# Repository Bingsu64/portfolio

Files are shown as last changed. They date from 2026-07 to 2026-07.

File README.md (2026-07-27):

# Portfolio
This repository contains design files from student engineering projects at [ARIS (Akademische Raumfahrt Initiative Schweiz)](https://aris-space.ch/).
I have only included files and reports where I have 100% ownership and have at least been reviewed for manufacturing.

## Project HELVETIA - Recovery Electronics
[This folder ](https://github.com/Bingsu64/portfolio/tree/main/HELVETIA_REC_PCB)
contains the PCB schematic and layout files for the auxiliary power-switching and PWM-generation board used in the recovery system of our hybrid sounding rocket for SACUP 2022 (where the team placed 2nd in the 30k ft category). Additionally, a test report has been included detailing our process to test and validate the system to assure reliability and system safety.

## Project ODYSSEY - Avionics
[This folder ](https://github.com/Bingsu64/portfolio/tree/main/ODY_5V_Board)
contains the PCB design files for the block and schematics documentation of a 5V power module for a modularized flight computer architecture of a Karman-Line, bi-liquid rocket system.
Even though it was never manufactured due to premature project conclusion due to budget constraints, it had been peer-reviewed and improved drastically for legibility and documentation purposes.

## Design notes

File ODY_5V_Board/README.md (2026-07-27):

# Project ODYSSEY
This folder contains the PCB schematic and block documentation for a modular 5V power module designed for a modularized flight computer architecture 
intended for a Karman-Line, bi-liquid rocket system.  

Status: R&D / Preliminary Design Phase (Peer-Reviewed, Unmanufactured due to project budget constraints)

## ODYSSEY Avionics
Project ODYSSEY was an ambitious flagship initiative at ARIS aimed at developing a bi-liquid rocket to reach the Karman line (100km altitude).  
 - To support a complex, modularized flight computer architecture, reliable local power regulation was essential.
 - My specific ownership focused on designing the 5V power module block, ensuring stable power delivery and low noise sensitivity
 - Further focus on reliability by implementing redundancy, monitoring, and diagnostics capabilities for fault handling

|  |
| :--: |
| *Figure 1: Block Diagram of the 5V Power Module* |

## Design Readiness
Although the project concluded prematurely due to budget constraints and organizational restructuring, before physical manufacturing could take place,
the schematic underwent a rigorous formal peer-review with senior ARIS team members and technical leads. Based on review feedback, the documentation and net-labeling were drastically improved for legibility, component footprint verification, and manufacturability.

## Final Learnings
 - Learned how to design power electronics strictly to specification and system requirements before physical hardware ever exists.
 - Gained valuable experience defending schematic architecture, component choices, and safety margins during peer-review gates.

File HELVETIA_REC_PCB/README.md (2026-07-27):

# Project HELVETIA
I designed and validated the auxiliary recovery PCB for Project HELVETIA responsible for power distribution, deployment actuation, and servo PWM generation for the recovery system.
Project HELVETIA's mission was to successfully build, launch, and safely recover our rocket at the Spaceport America Cup 2022 (SACUP). 
It was designed to reach an apogee of 30,000ft with a total impulse of 40,960Ns.

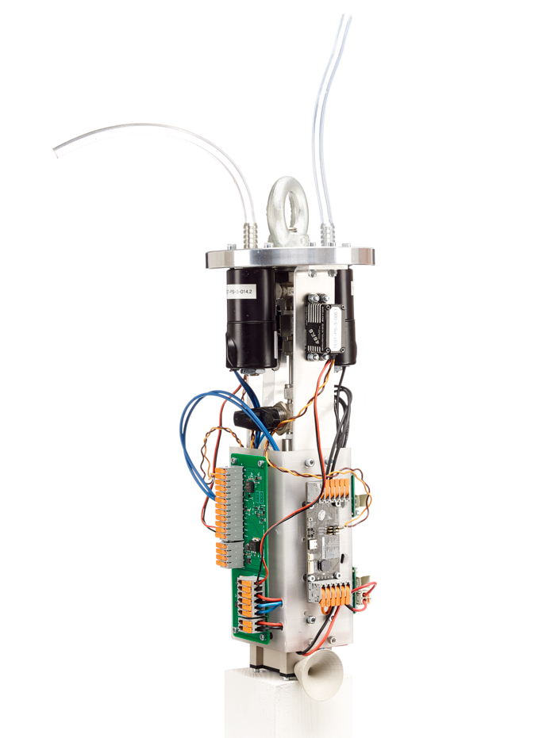
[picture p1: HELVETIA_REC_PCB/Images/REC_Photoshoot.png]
|  |
| :--: |
| *Figure 1: Picture of the sub-bulkhead assembly of the recovery fairing* |

## Recovery System
To briefly contextualize, here is an overview of the recovery system section:
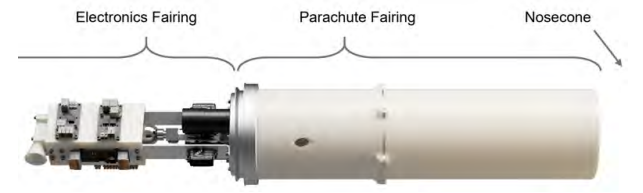
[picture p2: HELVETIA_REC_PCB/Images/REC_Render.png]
|  |
| :--: |
| *Figure 2: Render of the Recovery Section of the rocket* |

After apogee detection, the drogue parachute is deployed by CO2 separation of the nosecone. This is actuated by solenoid valves powered through switching MOSFET's on the PCB.
For the main parachute deployment, servo motors are controlled to pull open a snap shackle mechanism. They are controlled by a PWM signal generated by the board.
Due to the competition requirements, our team utilized a Commercial Off-The-Shelf (COTS) flight computer for primary sensor logging.
To bridge the actuation and power needs, I designed a dedicated auxiliary board with Altium Designer, responsible for:
 - Power Distribution and Switching: Safely arming the system and switching power rails for deployment mechanisms
 - PWM Generation: Creating precise pulse-width modulation signals for servo motor control without requiring an onboard microcontroller (due to chip shortage)
 - Mission Reliability: Total Redundancy between the COTS and Student Researched and Developed (SRAD) flight computer to ensure reliable and safe recovery operations

Note on Avionics Architecture: While SACUP regulations mandated the use of a standard COTS flight computer (TeleMega) for official mission data logging, 
our project leadership also instituted an internal requirement to test a newly student-researched and developed (SRAD) flight computer. 
Project HELVETIA successfully served as the foundational flight-test vehicle, providing the critical empirical telemetry needed to prove the reliability 
of that SRAD flight computer to regulatory officials. Within this architecture, my direct ownership and design scope focused entirely on the auxiliary power-switching, 
PWM generation, and robust actuation hardware required for safe recovery execution.

## System Integration & Flight Validation
This auxiliary hardware was integrated directly into the rocket's recovery loop as a mission critical interface to manage physical deployment for both drogue and main parachute.
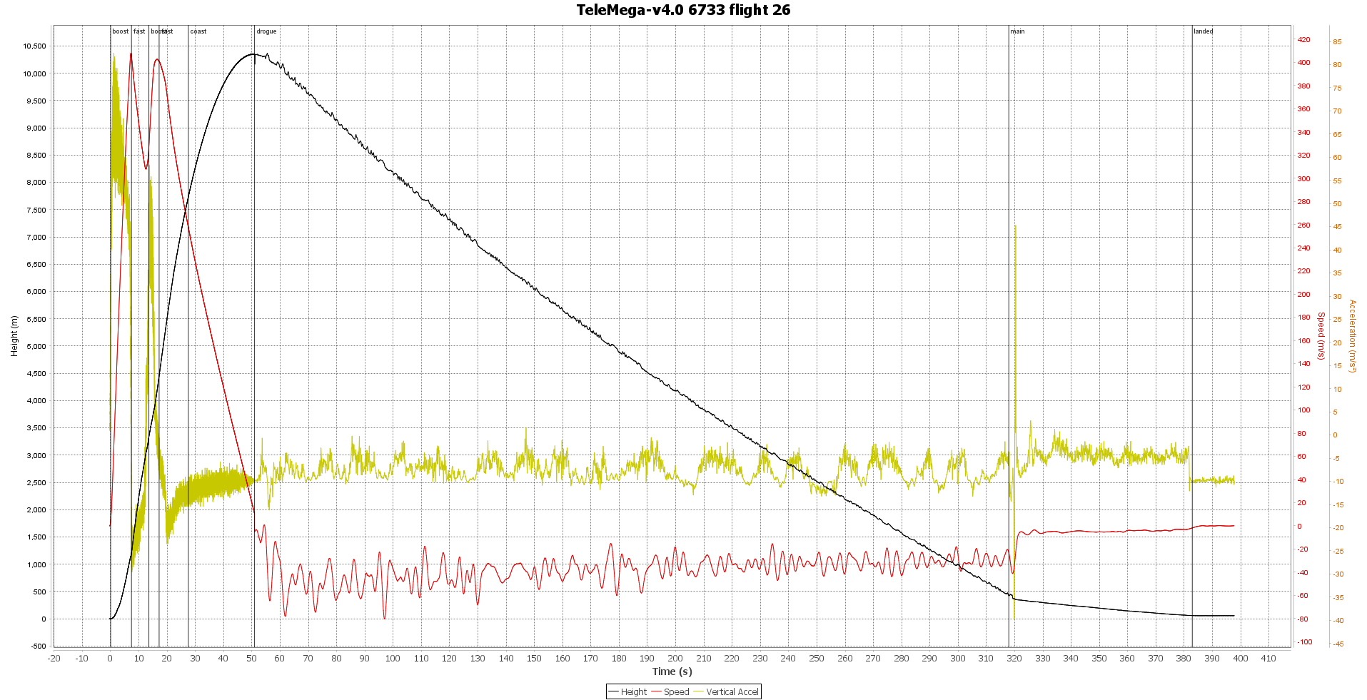
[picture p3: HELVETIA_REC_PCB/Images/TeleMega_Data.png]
|  |
| :--: |
| *Figure 3: COTS flight computer telemetry data of the flight during the SACUP competition* |

 - Beyond standard telemetry verification, our primary design and operational goal for the recovery team was simple: make a recovery system that just works
 - As the first team in ARIS history to successfully and safely land and recover our rocket, every testing procedure, safety checklist, and power-switching constraint was engineered around eliminating single-point failures
 - Flight data and test logs confirmed that the auxiliary power and actuation hardware executed deployment flawlessly under real flight conditions, securing 2nd place in the 30k ft category at SACUP 2022

## Key Takeaways & Engineering Lessons
 - Harsh Environment Design: Learned firsthand how physical vibrations and high-g forces dictate component selection, trace sizing, and layout constraints
 - System Simplicity: Saw the direct impact on system robustness by making a design simple
 - End-to-End Ownership: Managed the full lifecycle of a mission-critical PCB from initial schematic capture and layout to manufacturing, assembly, and bench/field verification

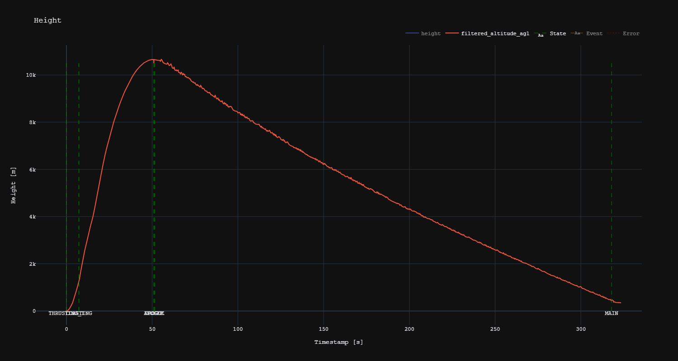
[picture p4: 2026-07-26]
HELVETIA_REC_PCB/Images/newplot.png

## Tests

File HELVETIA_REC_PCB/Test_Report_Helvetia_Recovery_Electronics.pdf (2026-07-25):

Title: | Recovery Electronics
ID: | ReEl01
Issue: | 1
Date: | 26-07-24
Page: | 1 of 42

© Project HELVETIA. This document shall not be used for other purposes than those for which it was

established. No unauthorized distribution, dissemination or disclosure.

# Recovery Electronics Full Test

Title: | Electronics Full Test Report
Project: | HELVETIA
Filename: | Test_Report_Helvetia_Recovery_Electronics
Prepared by: | Fabian Kolodziej, Dongkyu Lee, Xuanting Meng
Checked by: | Alexandros Karadeloglou, François Martin-Monier

## TEST DATA

General Information

Test – ID: | ReEl01
Subteam: | Recovery | Subsubteam: | Electronics

Introduction

This test report includes all functionality, quantity and partial system tests that have

been conducted during the testing campaign. These also encompass partial

system analyses with a focus on electronics for tests that already have a general

test report. The report aims to present procedural aspects, test data and explain

design choices.

Date: | 26-07-24
Page: | 2 of 42

© Project HELVETIA. This document shall not be used for other purposes than those for which it was

## Table of Contents

Inhalt | Error! Bookmark not defined.

Date: | 26-07-24
Page: | 3 of 42

© Project HELVETIA. This document shall not be used for other purposes than those for which it was

## 1 TEST Preparation

## 1.1 Attending People

Name | Function
Fabian Kolodziej | Test Execution
Dongkyu Lee | Test Logging
Xuanting Meng | Test Execution

## 1.2 Safety Concept

### 1.2.1 Safety Gear

Gear | Further specifications | Status
Protective Glasses | | ☐
Protective Gloves | | ☐

## 1.3 Materials

### 1.3.1 Rocket Parts

Part/Assembly | Responsible Subteams | Status
Auxiliary Board | Recovery | ☐
Flight Computers | Recovery | ☐

Date: | 26-07-24
Page: | 4 of 42

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

Arming Electronics | Recovery | ☐
Valves, Servo Motors | Recovery | ☐
Power Switching Boards | Recovery, Avionics | ☐

### 1.3.2 Equipment

Equipment | Further specifications | Status
Multimeter | A portable oscilloscope which doubles as a multimeter | ☐
LiPo-Charger | | ☐
Oscilloscope | | ☐
Laptop | With required software and cables | ☐
Camera | | ☐
Bench Power Supply | | ☐

## 1.4 Location

Short Description of the Test Location

The test locations were different for each test performed. Functionality and quantity tests

were all conducted in free working spaces that provide basic electronics testing

equipment.

Date: | 26-07-24
Page: | 5 of 42

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

Provided at the Test Location

Testing equipment which includes the equipment stated in 1.3.3.

Possible Environmental influx to the Test at the Location and vice versa

No general influx on functionality.

Signal interference by devices and metallic structures in the vicinity.

### 1.4.1 Environmental Conditions

| Actual values | Acceptable range
Weather | Inside | Any
Temperature | 20°C | Comfortable for People

Other notes

### 1.4.2 Comparison to the Launch Condition

Different Location -> Different GPS Signals

Sand could get into connectors so that assembly could prove to be more difficult

Date: | 26-07-24
Page: | 6 of 42

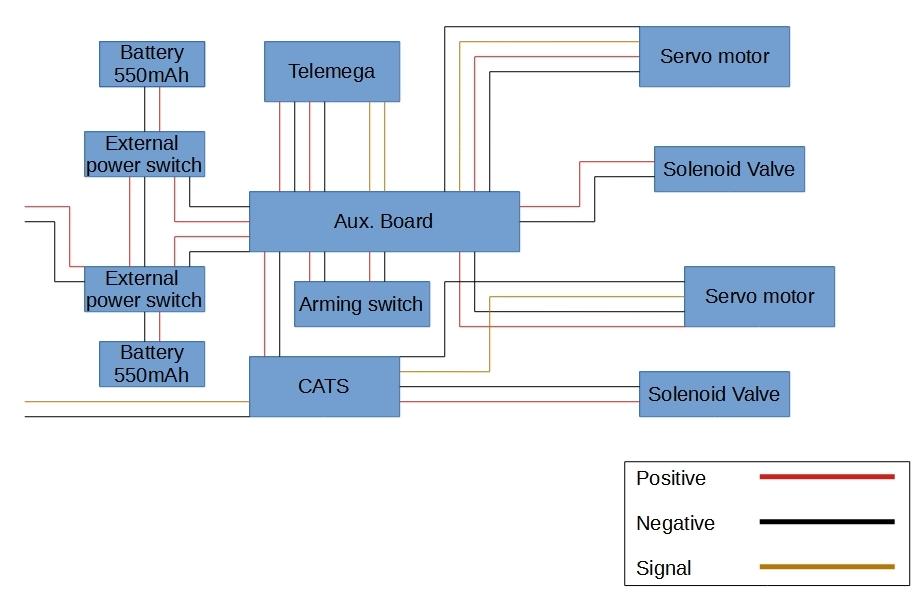
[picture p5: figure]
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

## 1.5 Setup

Setup

Description

The system consists of one auxiliary board, two power switching boards each connected

to a separate battery that power one COTS (TeleMega) and one SRAD (CATS) flight

computer respectively. Both arming switches are connected to the auxiliary board that

houses two separated systems. The servo motors are attached to aluminium L-pieces that

are connect the electronics holder to the bulkhead.

The power for both valves and servos are connected to the auxiliary board, except the

solenoid valve on the SRAD side which is directly connected to the CATS (SRAD) flight

computer.

The arming switches are housed in an arming case that is attached at the bottom of the

holder.

Wiring Diagram

Date: | 26-07-24
Page: | 7 of 42

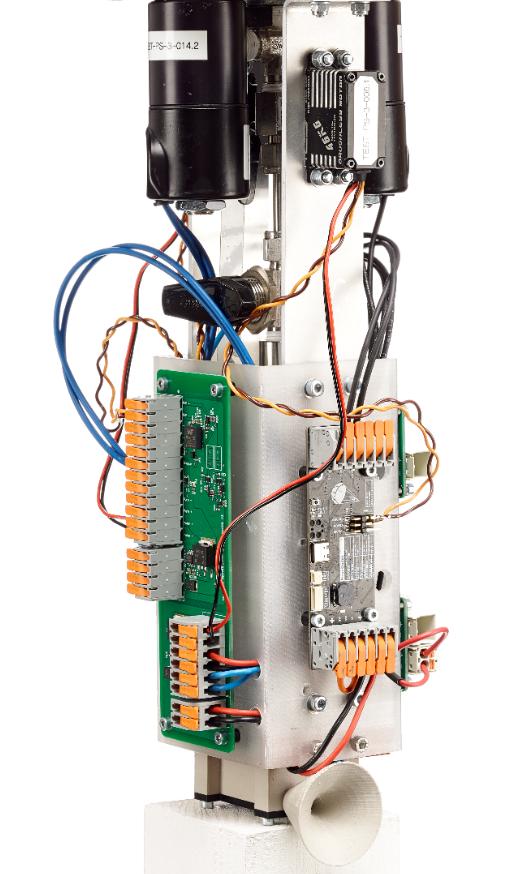
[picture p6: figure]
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

Picture

### 1.5.1 Pre-Test Checks for the Setup

What needs to be checked to ensure the success of the test?

Item | Comments | Status
Assembly Procedure | | ☐
Arming Checklist | | ☐

Date: | 26-07-24
Page: | 8 of 42

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

## 2 MAIN TESTS

## 2.1 Functionality Tests

Setup:

For general functionality tests of our system, the relevant parts will be

assembled as necessary. The basic setup is described and explained in the

previous chapter. Each unique setup is illustrated with a picture at the

beginning of each individual test subchapter.

Purpose of Test:

The following tests are performed to test and confirm the capability and

functionality of the system. This is to identify any flaws in the current concept

and design. A functionality test of the entire system requires a variety of

different tests that validify small parts of the system so that problems can only

occur in isolated and controlled instances.

### 2.1.1 Auxiliary Board Functionality Test

Purpose of Test:

During the armed state, all in- and outputs of the board are strictly defined and

need to be within an expected range. As such, probing the board for its

voltage levels and potential bridges is imperative to identify any electrical

errors that could later lead to greater failure modes and cause harm to

connected devices.

Date: | 26-07-24
Page: | 9 of 42

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

Functionality Checklist:

Procedure | Value | Status
Battery Connector Inputs ‘+’ and ‘-‘ must not be bridged | Twice for both circuits | ☐
After connecting batteries to input, voltage between input pins needs to be measured | 12V | ☐
Test arming circuits by shorting ‘Arm+’ and ‘Arm-‘ with a jumper cable | 12V | ☐
Measure voltage between ‘CATS+’ and ‘CATS-‘ | 12V | ☐
Measure voltage between ‘Motor+’ and ‘Motor-‘ | 12V | ☐
Measure voltage between ‘Pyro+’ and ‘Pyro-’ | 12V | ☐
Measure voltage between both ‘Valve’ connectors | 0V | ☐
Measure voltage between ‘Tele+’ and ‘TM-’ | 3.7V | ☐

Results:

Parameters | Value
U(+, -) | 12.2V (LiPo)
Arming Circuit | Non-functional
U(CATS+, CATS-) | 9.78V
U(Motor+, Motor-) | 9.78V
U(Pyro Battery, GND) | 9.78V

Date: | 26-07-24
Page: | 10 of 42

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

U(12V, GND) | 9.78V
U(3.7V, GND) | 3.716V
LED’s | All Functional

Conclusion:

The arming did not work as intended when opening and shorting the arming

inputs. The MosFET’s did not open when the arming switches were turned off.

This lead to the assumption that either the MosFET’s were malfunctional or

the circuit design had an issue. It turns out that the manufacturer PCB design

files were wrong. The Drain and Source were interchanged for both

schematics and footprints so that the MosFET effectively let current through its

protector diode.

Mitigation:

After identifying the issue, the amount of LED’s has been increased for safety

and easier problem detection. Furthermore, the schematics and footprints

have been corrected in a new version of the board (RecoveryBoard_V3).

Results of Retest of V2 boards:

Parameters | Value
U(+, -) | 12.2V (LiPo)
Arming Circuit | Functional
U(CATS+, CATS-) | 12V

Date: | 26-07-24
Page: | 11 of 42

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

U(Motor+, Motor-) | 12V
U(Pyro Battery, GND) | 12V
U(12V, GND) | 12V
U(3.7V, GND) | 3.716V
LED’s | All Functional

Conclusion:

With the new version of the boards, the arming circuit was functional and the

MosFET switched with no issues. Now instead of the questionable 9.7V, we

got the full 12V provided. As such, the full general power functionality of the

board was confirmed.

### 2.1.2 PWM Modulation Test

Purpose of Test:

For the deployment of the main parachute, the second deployment event, a

pulse-width modulation (PWM) signal is used. This in turn controls the position

of the servor motor arm. As the PWM outputs on the TeleMega (COTS) flight

computer have not been fully implemented yet, a PWM modulator circuit has

been implemented on the auxiliary board and needs to be tested. Due to the

servo motors missing datasheets, the PWM range is yet to be identified. For

this reason, trimmers have been implemented on the board to match the PWM

signal to any range between 0% to 100%.

Date: | 26-07-24
Page: | 12 of 42

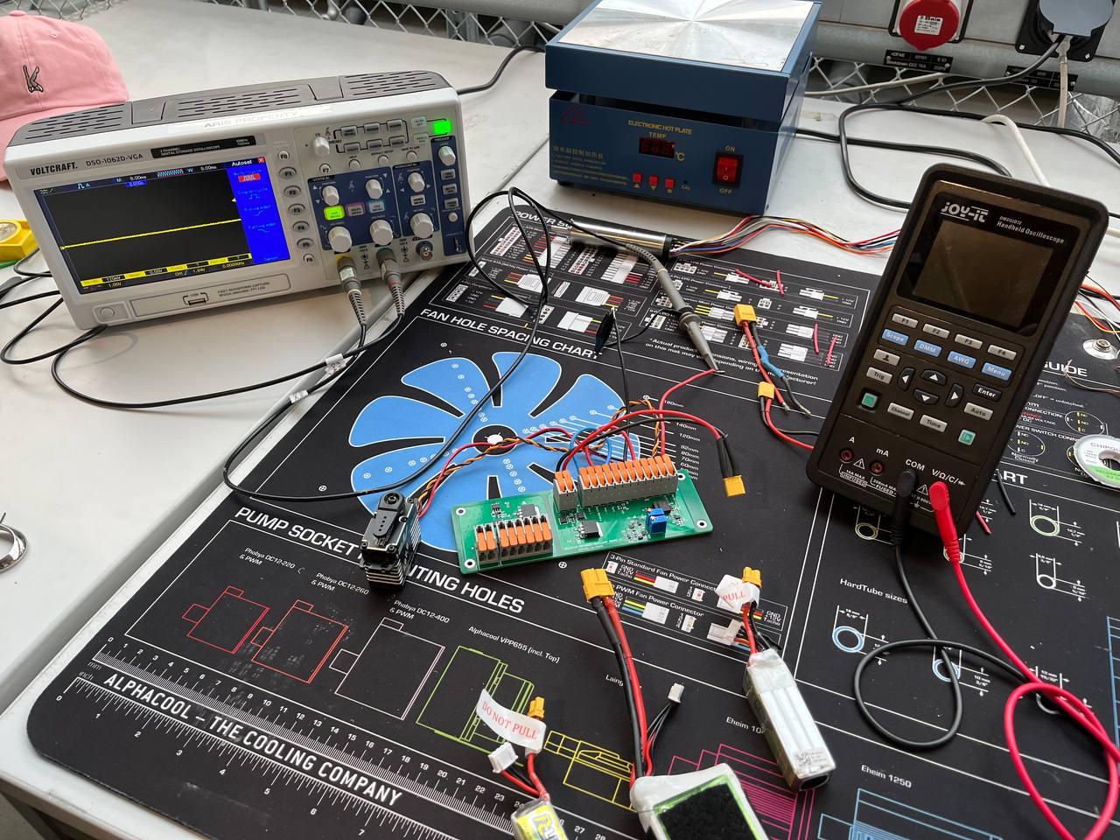
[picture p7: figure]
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

Setup change:

Figure 2.1 Servo Motor PWM Input connected to an oscilloscope

PWM Modulation Test Procedure:

Procedure | Value | Status
Pull the Arming Pin | System Armed | ☐
Connect an oscilloscope to the connectors ‘Servo’ and ‘GND’ | | ☐
Measure the signal for position 1 (Default position) | Servo Default | ☐

Date: | 26-07-24
Page: | 13 of 42

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

Turn the trimmer to see changes and try to match signal to 5% duty (usual minimum value of conventional PWM signal ranges) | | ☐
Connect connector ‘Pyro’ to ‘GND’ | | ☐
Measure the signal for position 2 (Deployment active) | Servo Deployed | ☐
Turn the trimmer to see changes and try to match signal to 10% duty (usual maximum value of conventional PWM signal ranges) | | ☐
Insert Arming Pin | System Disarmed | ☐

Results:

Parameters | Value
Frequency | 50.12Hz
Voltage Logic High | 3.7V
Voltage Logic Low | 0V
PWM Duty Cycle 1 | 15%
PWM Duty Cycle 2 | 25%
Servo Arm Position 1 | Out of Range
Servo Arm Position 2 | Out of Range
MosFET 1 | Non-Functional
MosFET 2 | Functional

Date: | 26-07-24
Page: | 14 of 42

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

Conclusion:

As the switching between the ‘Default’ and ‘Deployed’ modes was not working

as intended, the switching power MosFET’s were investigated. It turned out

that the MosFET 1 being non-functional was due to the gate driver. The output

of the gate driver was lower than what it stated in the datasheet, which led to

the MosFET 1 switch never opening and as a result, never switching.

Therefore, for ‘Deployed’ mode, when ‘Pyro’ is grounded, the resistors were

set in parallel and thus duty increased instead of getting controlled by a set

trimmer.

Furthermore, even during ‘Default’ mode in which MosFET 2 is open and

MosFET 1 is closed, the duty was out of the operating range of the servos.

The cause is the resistor at the ‘MOD’ input of the LTC6992 IC being too large

which led to a higher voltage which in turn leads to higher duties.

Mitigation:

By removing the 10k resistor at the input of the gate driver, both voltages on

input and output sides of the driver are increased. Consequently, the voltage

difference between Gate and Source lies below the threshold voltage of 0.8V

and the MosFET switches.

As the voltage across the resistor at the MOD input of the LTC6992 IC and the

duty are closely related, changing the 1.2k resistor to a 330Ohm should also

lower the resulting duty and thus the duties should enter the operating range

of the servo motors.

Results of Retest (V2):

Parameters | Value
Frequency | 50.12Hz

Date: | 26-07-24
Page: | 15 of 42

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

Voltage Logic High | 3.7V
Voltage Logic Low | 0V
PWM Duty Cycle 1 | 2%
PWM Duty Cycle 2 | 13%
Servo Arm Orientation 1 | Up
Servo Arm Orientation 2 | Down
MosFET 1 | Functional
MosFET 2 | Functional

Conclusion:

With the new changes, the PWM modulating circuit on the auxiliary board V2,

successfully switched and controlled the servo motors so that we got two

stable positions for the servo motor arms.

### 2.1.3 Ground Tests

Purpose of Test:

To ensure safe and reliable deployment of both drogue and main parachutes,

the system needs to be sufficiently tested on the ground before it may be used

in any real flight test. The capability of the system to carry out the mission in its

full capacity is essential and most of it can be tested on the ground.

Date: | 26-07-24
Page: | 16 of 42

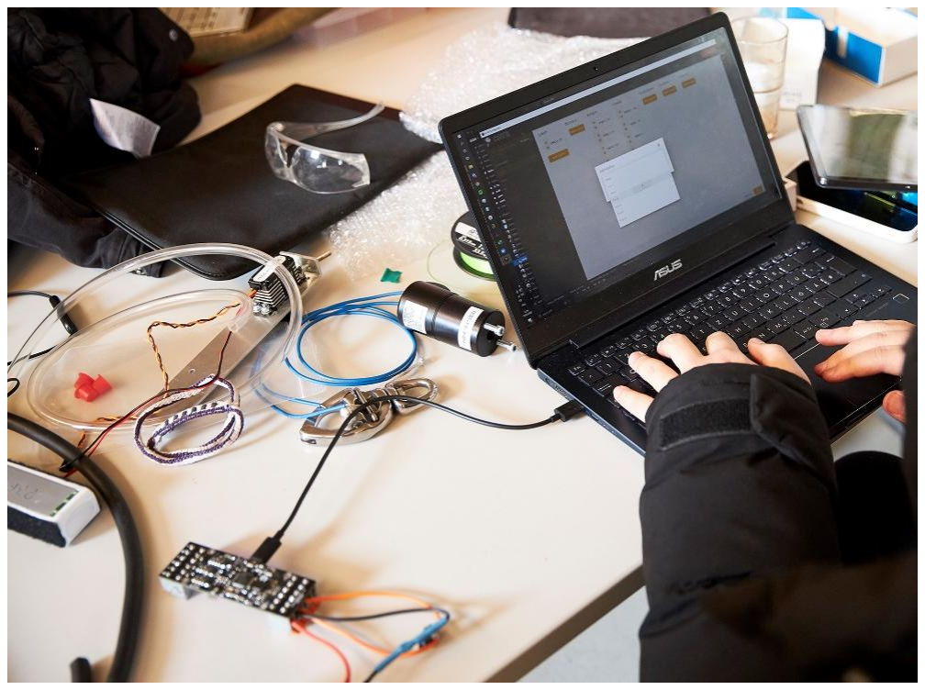
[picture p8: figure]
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

The CATS (SRAD) has been tested by setting up a timer to trigger the events

by logic. As for the TeleMega (COTS), all ground tests can be done by

manually triggering the pyro channels in question.

Setup Change:

Figure 2.2 Programming CATS (SRAD) FC for ground tests. The valves and Motors can be directly connected to flight computer.

Ground Test Procedure (CATS):

Procedure | Comments | Status
Configure CATS (SRAD) Flight Computer (Ground Test configuration) | | ☐
Pull the Arming Pin | System Armed | ☐
Wait for Ready State of the CATS Flight Computer | | ☐
Wait 10 seconds for Solenoid Valve Actuation | Drogue Deployed | ☐

Date: | 26-07-24
Page: | 17 of 42

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

Wait 5 more seconds for Servo Motor Actuation | Main Deployed | ☐
Insert Arming Pin | System Disarmed | ☐

Results:

Parameters | Value
Valve Actuation | Successful (3s)
Servo Motor Actuation | 30° to 150°

Conclusion:

Valve actuation worked flawlessly for 3 seconds as configured. The servo

motor actuation does not cover the entire range of the servo. This however

was expected, as the duty range of the CATS PWM output is from 5% to 10%

whereas the servos seem to operate from 2% to 13%. This is the estimated

range from the results obtained in the PWM Modulation Test.

With the system connected to the servos and the snap shackle, the range of

30° to 150° was still enough to open the snap shackle. Furthermore, by

shortening the lines between the snap shackle and the servos, this difference

in frequency range can be overcome.

Ground Test Procedure (TeleMega):

Procedure | Comments | Status
Connect TeleMega (COTS) to a notebook computer via Micro USB cable and orient the board horizontally. | | ☐

Date: | 26-07-24
Page: | 18 of 42

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

Pull the Arming Pin | System Armed | ☐
Confirm Idle State and Battery Percentage reported by beeps. | | ☐
Select Manual Pyro Trigger on the TeleMega Software Interface | | ☐
Fire Pyro Channel D to actuate Solenoid Valve | Drogue | ☐
Fire Pyro Channel B to actuate Servo Motor | Main | ☐
Insert Arming Pin | System Disarmed | ☐

Result:

Parameters | Value
Valve Actuation | Successful (3s)
Servo Motor Actuation | 0° to 180°

Conclusion:

For the TeleMega, ground tests were performed by manual trigger which in

this case worked flawlessly. Due to the nature of manual triggers, the events

could only be triggered sequentially. However, that corresponds to the needs

of the mission and the TeleMega cannot in either way trigger two events

simultaneously. Therefore, the technical capabilities and functionality of the

TeleMega combined with the auxiliary board could be validated.

Date: | 26-07-24
Page: | 19 of 42

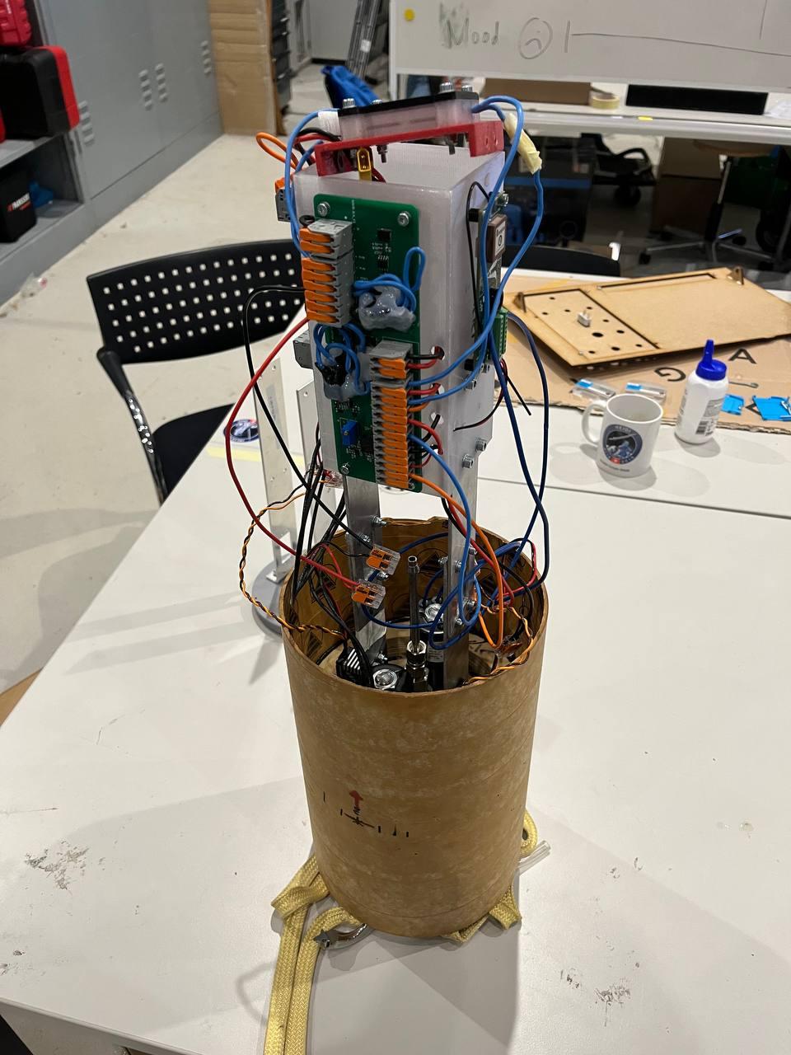
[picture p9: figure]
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

### 2.1.4 Lift-off Detection and Flight Mode Test

Purpose of Test:

Whilst the ground tests provide the validation of the technical capabilities of

the design and the system components, the telemetry and logic components

have not been tested in combination with the mentioned system. Hence, it

makes sense to simulate a flight environment as much as possible and test

the event-triggering.

Setup Change:

Figure 2.3 Setup of Argos Launch. Most convenient and structurally rigid setup for simulated flight mode tests.

Date: | 26-07-24
Page: | 20 of 42

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

Lift-off and Flight Mode Test Procedure (CATS):

Procedure | Comments | Status
Configure CATS (SRAD) Flight Computer (Flight Test configuration) | | ☐
Pull the Arming Pin | System Armed | ☐
Confirm ‘Ready’ state of CATS | Ready | ☐
Pull the system up with force | | ☐
Confirm Valve Actuation | 3 seconds | ☐
Confirm Servo Actuation | Down | ☐
Insert the Arming Pin | System Disarmed | ☐

Results:

Parameters | Value
Lift-off Detection | Successful
Valve Actuation | 3 seconds
Servo Actuation | 30° to 150°
Arming | Successful

Conclusion:

As the CATS (SRAD) flight computer does not provide direct methods for

manually triggering deployment events, the flight mode did not differ much

from the afore performed ground tests. This test was mostly to see whether

Date: | 26-07-24
Page: | 21 of 42

© Project HELVETIA. This document shall not be used for other purposes than those for which it was the Lift-off detection worked in combination with the telemetry and logic of the

CATS flight computer.

Lift-off and Flight Mode Test Procedure (TeleMega):

Procedure | Comments | Status
Configure TeleMega (COTS) Flight Computer (Flight Test configuration) | | ☐
Pull the Arming Pin | System Armed | ☐
Confirm ‘Flight Ready’ state of TeleMega | Flight Ready | ☐
Pull the system up with force | | ☐
Confirm Valve Actuation | 3 seconds | ☐
Confirm Servo Actuation | Down | ☐
Insert the Arming Pin | System Disarmed | ☐

Results:

Parameters | Value
Lift-off Detection | Successful
Valve Actuation | Malfunctional
Servo Actuation | Non-Nominal, Shaky Servo Arm
Arming | Successful

Date: | 26-07-24
Page: | 22 of 42

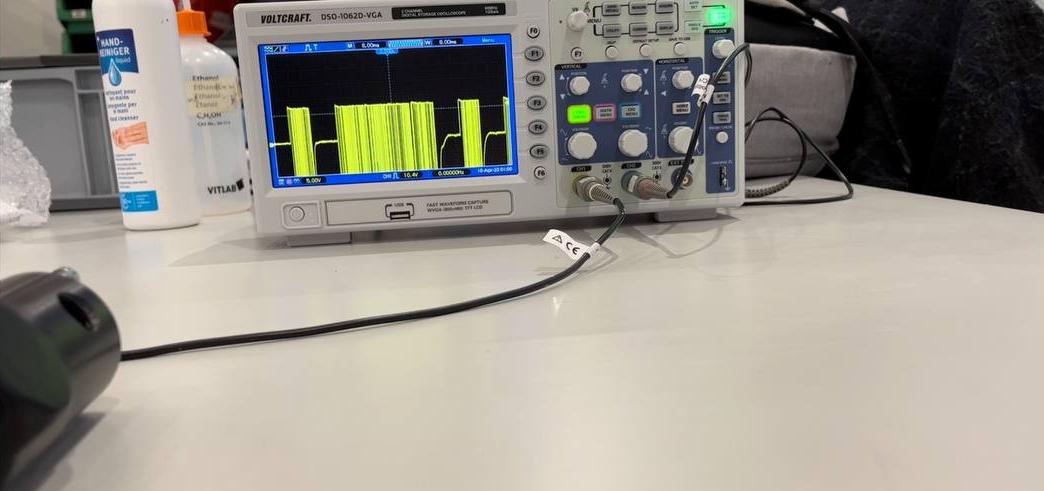
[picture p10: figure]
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

Observation:

Both deployments did not operate nominally. For both the valve and the servo

motor actuation, the pyro channel signals on the TeleMega worked in a

“PWM”-like state with high frequency. Such a behaviour would prevent the

valves from releasing enough CO2. In addition to that, the release of the snap

shackle cannot be guaranteed due to the shaky nature of the servo arms

turning. Thus, the test is considered a failure and the source of the problem

needs to be identified as soon as possible. In this state, redundancy of the

system is not given.

Figure 2.4

Furthermore, during some of the tests, a MosFET of one of the pyro channels

blew up and shorted the pyro circuit (Pyro channel C on the TeleMega 4.0 and

the 5.0 in particular). This alone does not impact the mission, in case of such

behaviour during a rocket launch, as this only happens after valve actuation.

As such, after valve actuation, the valve would simply not close anymore

which means nosecone ejection is successful. However, that pyro channel

would not be operational again which leads to only 3 out of 4 pyro channels

Date: | 26-07-24
Page: | 23 of 42

© Project HELVETIA. This document shall not be used for other purposes than those for which it was being operational on each TeleMega unit at the time of writing this report. At

least 2 are necessary for a successful mission.

Mitigation:

The circuit lacked a flyback diode for protection in case inductive loads

damaging the MosFET’s were the reason for the shorting. Though the ground

tests worked without problems, it seems the high frequency switching caused

some cumulative damage to the MosFET’s. This however has not happened

to the pyro channels connected to the servo motors implying that it is the

missing flyback protection causing the damage.

As for the high frequency switching itself, different batteries seem to cause

different behaviour when observing the servo motor arms turning.

Battery Voltage | Turn Before Malfunctioning
11.08V | 90°

12.59 150°

The higher battery voltage led to a longer interval before the high frequency

switching started. Thus, it was inferred that there was a correlation between

the malfunctioning MosFET’s and the input voltage.

Apart from the internal gate signal which is regulated to a stable 3.28V by an

LDO, the gate of the pyro channel MosFET’s is also controlled by a differential

dual comparator. It compares and pulls the gate down to ground for input

power supplies at for less than 3.5V. As such, the pyros are locked and cannot

fire at a voltage smaller than 3.6V, presumably due to voltage drop-offs and

real-world circumstances. The TeleMega manual states that a Li-Po battery

must provide a voltage of equal to or higher than 3.8V for the ground station to

Date: | 26-07-24
Page: | 24 of 42

© Project HELVETIA. This document shall not be used for other purposes than those for which it was give a ‘GO’ status for launch. However, telemetry, logic and even the pyros

seem to fire at a power supply of the 3.716V the auxiliary board provided.

After testing for different power supply levels, it could be identified that the

high frequency switching only happened at 3.7V.

Battery Voltage | Test Result After 3 Consecutive Tests
3.6V | No Actuation
3.7V | High Frequency Switching Pyros
3.8V | Perfect Actuation

At 3.6V, the pyros did not fire at all, whereas at 3.8V, the pyros fired perfectly

for both valves and servos. After discussing this matter with the creators of the

TeleMega flight computer, this high frequency switching neither reflects

nominal behaviour nor any expected failure modes of the TeleMega. They also

stated that whilst the telemetry remains powered at power supply levels lower

than 3.8V, the pyros are supposed to be locked per design.

Conclusion:

After changing a resistor on the auxiliary board to increase the TeleMega

power supply from 3.716V to 4.4V, the pyros fired without problems. As the

high frequency switching did not occur in 10 consecutive attempts, the

possibility of it being linked to the auxiliary board has been ruled out. However,

as this seemed to be a phenomenon that only ever occurred at 3.7V, it could

be considered as mitigated by increasing the power supply voltage for the

TeleMega. It may be possible that the high frequency switching is a result of

the TeleMega reacting to a critical voltage and locking pyro channels.

Date: | 26-07-24
Page: | 25 of 42

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

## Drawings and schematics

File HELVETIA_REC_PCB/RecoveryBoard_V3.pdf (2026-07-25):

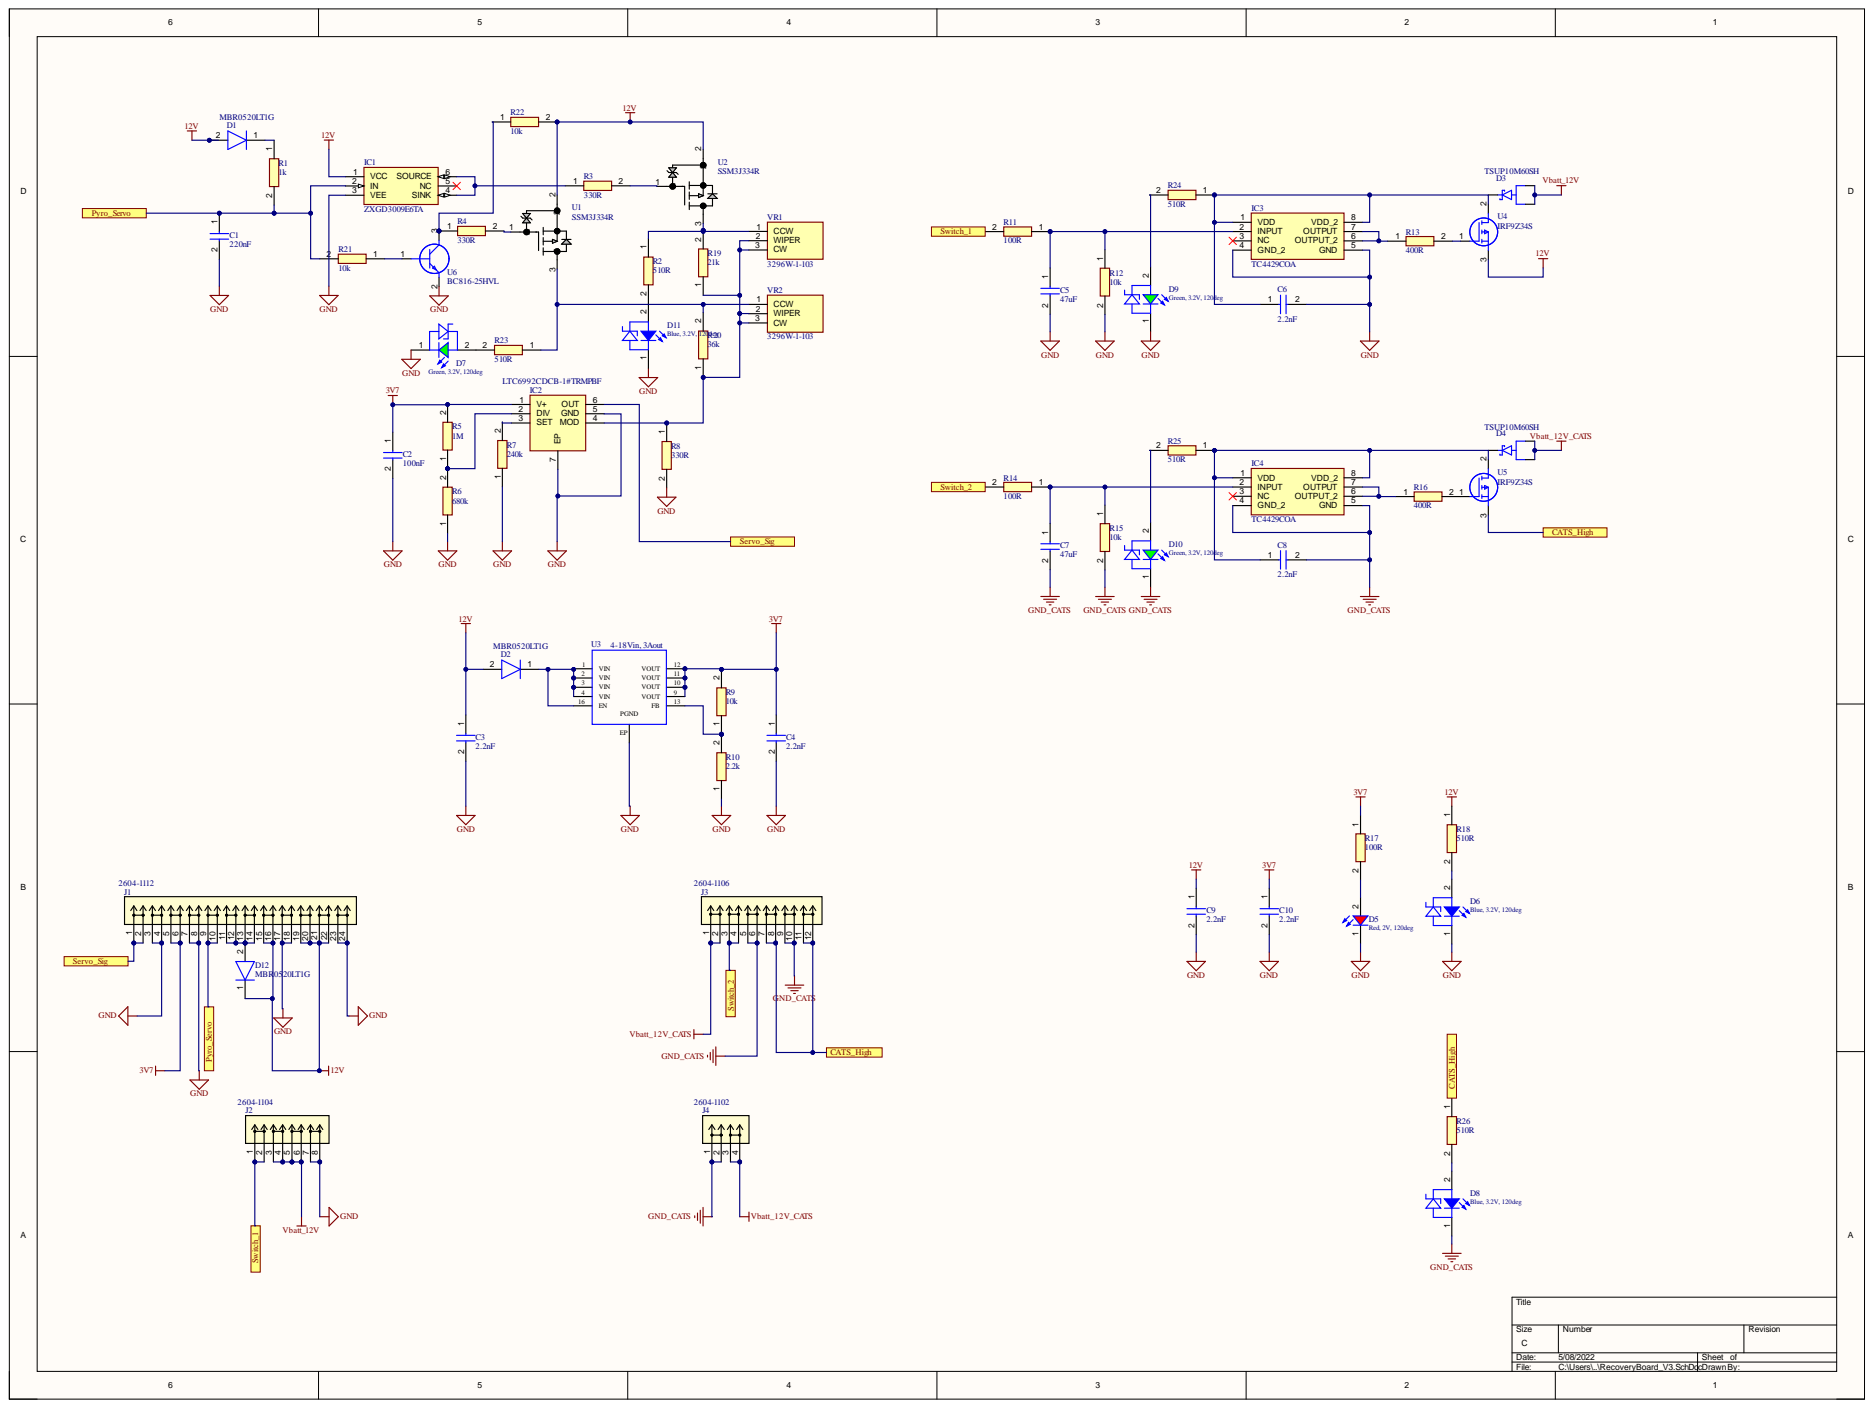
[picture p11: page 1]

Comment | Description | Designator | Footprint | LibRef | Quantity
220nF | Capacitor | C1 | CAPC1608X87N | 885012206036 | 1
100nF | Capacitor | C2 | CAPC1608X87N | 885012206036 | 1
2.2nF | Capacitor | C3, C4, C6, C8, C9, C10 CAPC1608X87N | | 885012206036 | 6
47uF | Capacitor | C5, C7 | CAPC1608X87N | 885012206036 | 2
MBR0520LT1G | Diode | D1, D2, D12 | SOD3716X135N | MBR0520LT1G | 3
TSUP10M60SH | | D3, D4 | DIO_TSUP10M60SH | TSUP10M60SH | 2
Red, 2V, 120deg | WL-SMCC SMD Mono-color Chip LED Compact, size 0603, Red, 2V, 120deg | D5 | WL-SMCC_0603_RS_VS_Y S | 150060RS73220 | 1
Blue, 3.2V, 120deg | WL-SMCC SMD Mono-color Chip LED Compact, size 0603, Blue, 3.2V, 120deg | D6, D8, D11 | WL-SMCC_0603_GS_BS | 150060BS73220 | 3
Green, 3.2V, 120deg | WL-SMCC SMD Mono-color Chip LED Compact, size 0603, Green, 3.2V, 120deg | D7, D9, D10 | WL-SMCC_0603_GS_BS | 150060GS73220 | 3
ZXGD3009E6TA | Integrated Circuit | IC1 | SOT95P285X140-6N | ZXGD3009E6TA | 1
LTC6992CDCB-1#TRMPBF | Integrated Circuit | IC2 | SON50P300X200X80-7N-D | LTC6992CDCB-1#TRMPBF | 1
TC4429COA | Integrated Circuit | IC3, IC4 | SOIC127P600X175-8N | TC4429COA | 2
2604-1112 | No Description Available | J1 | CONN_2604-1112_24_WAG | 2604-1112 | 1
2604-1104 | No Description Available | J2 | CONN_2604-1104_8_WAG | 2604-1104 | 1
2604-1106 | No Description Available | J3 | CONN_2604-1106_12_WAG | 2604-1106 | 1
2604-1102 | No Description Available | J4 | CONN_2604-1102_4_WAG | 2604-1102 | 1
1k | Resistor | R1 | RESC1608X55N | SDR03EZPF1003 | 1
510R | Resistor | R2, R18, R23, R24, R25, R26 | RESC1608X55N | SDR03EZPF1003 | 6
330R | Resistor | R3, R4, R8 | RESC1608X55N | SDR03EZPF1003 | 3
1M | Resistor | R5 | RESC1608X55N | SDR03EZPF1003 | 1
680k | Resistor | R6 | RESC1608X55N | SDR03EZPF1003 | 1
240k | Resistor | R7 | RESC1608X55N | SDR03EZPF1003 | 1
10k | Resistor | R9, R12, R15, R21, R22 | RESC1608X55N | SDR03EZPF1003 | 5
2.2k | Resistor | R10 | RESC1608X55N | SDR03EZPF1003 | 1
100R | Resistor | R11, R14, R17 | RESC1608X55N | SDR03EZPF1003 | 3
400R | Resistor | R13, R16 | RESC1608X55N | SDR03EZPF1003 | 2
21k | Resistor | R19 | RESC1608X55N | SDR03EZPF1003 | 1
36k | Resistor | R20 | RESC1608X55N | SDR03EZPF1003 | 1
SSM3J334R | No Description Available | U1, U2 | SOT-23F_TOS | SSM3J334R | 2
4-18Vin, 3Aout | MagI3C-VDRM Variable Step Down Regulator Module, LGA-16EP, 4-18Vin, 3Aout | U3 | LGA-16EP | 171031801 | 1
IRF9Z34S | MOSFET (P-Channel) | U4, U5 | TO-263(D2PAK) | IRF9Z34S | 2
BC816-25HVL | Transistor BJT NPN | U6 | SOT95P230X110-3N | BC816-25HVL | 1
3296W-1-103 | Variable Resistor | VR1, VR2 | 3296W1103 | 3296W-1-103 | 2

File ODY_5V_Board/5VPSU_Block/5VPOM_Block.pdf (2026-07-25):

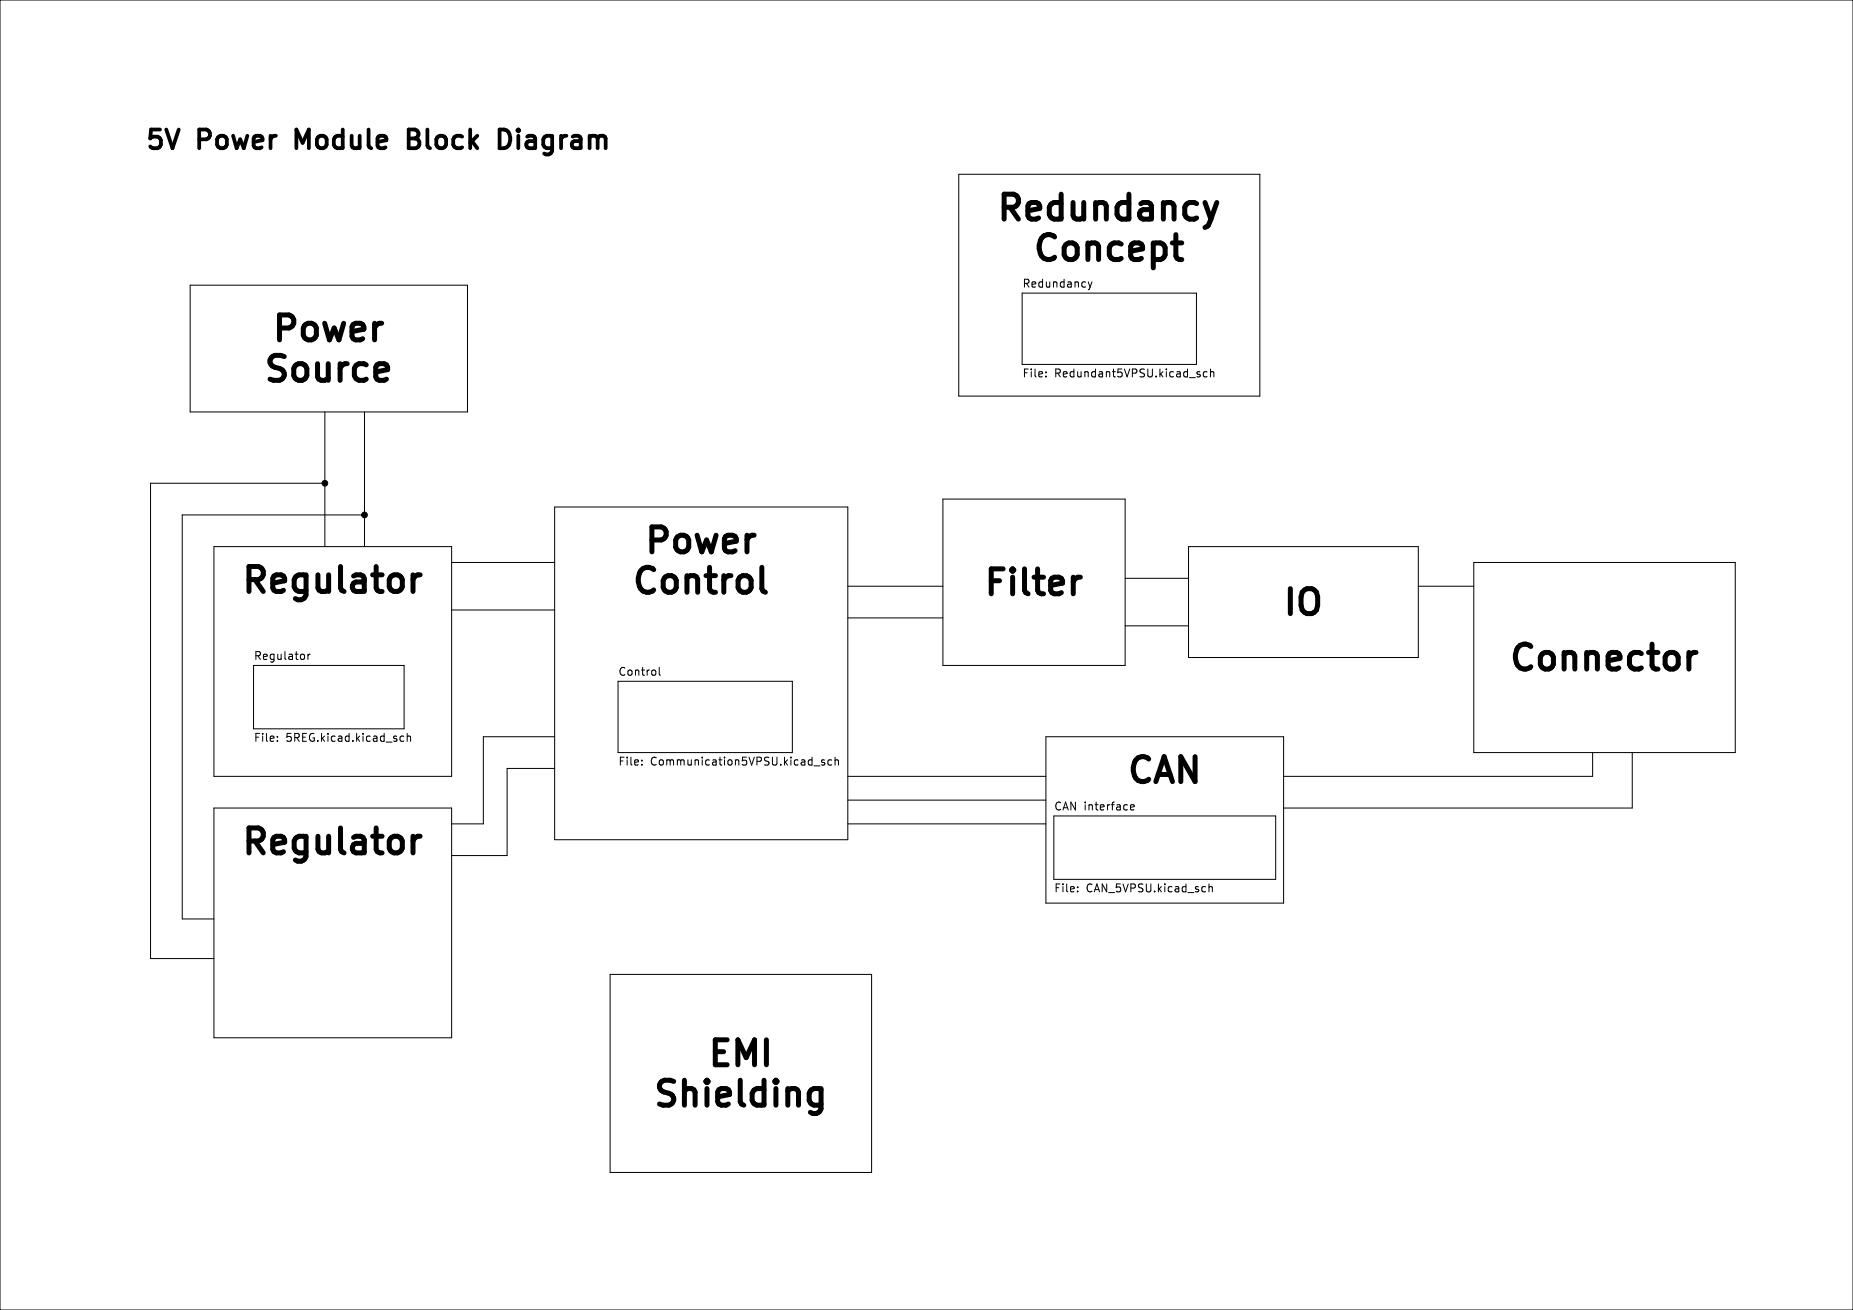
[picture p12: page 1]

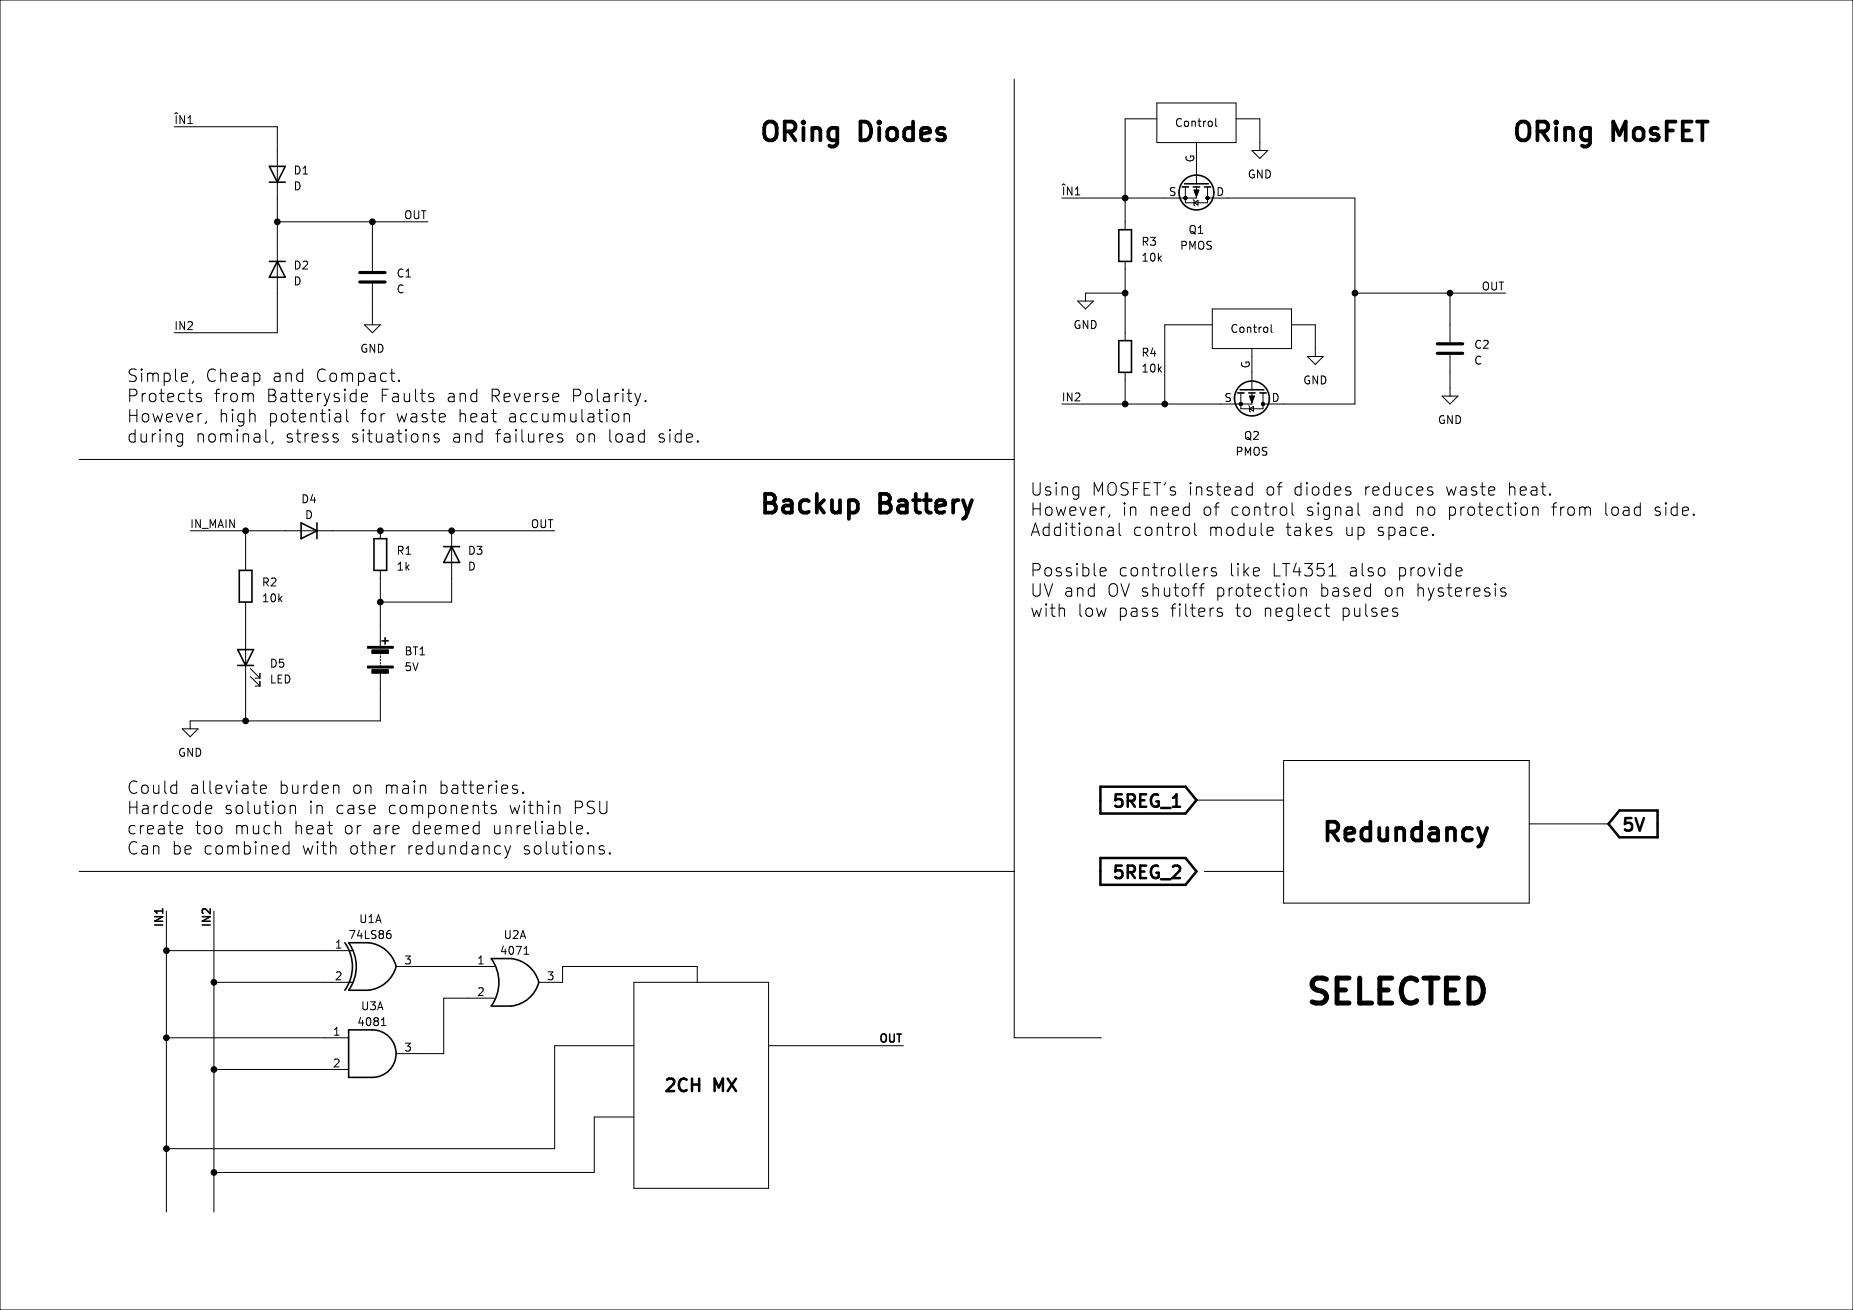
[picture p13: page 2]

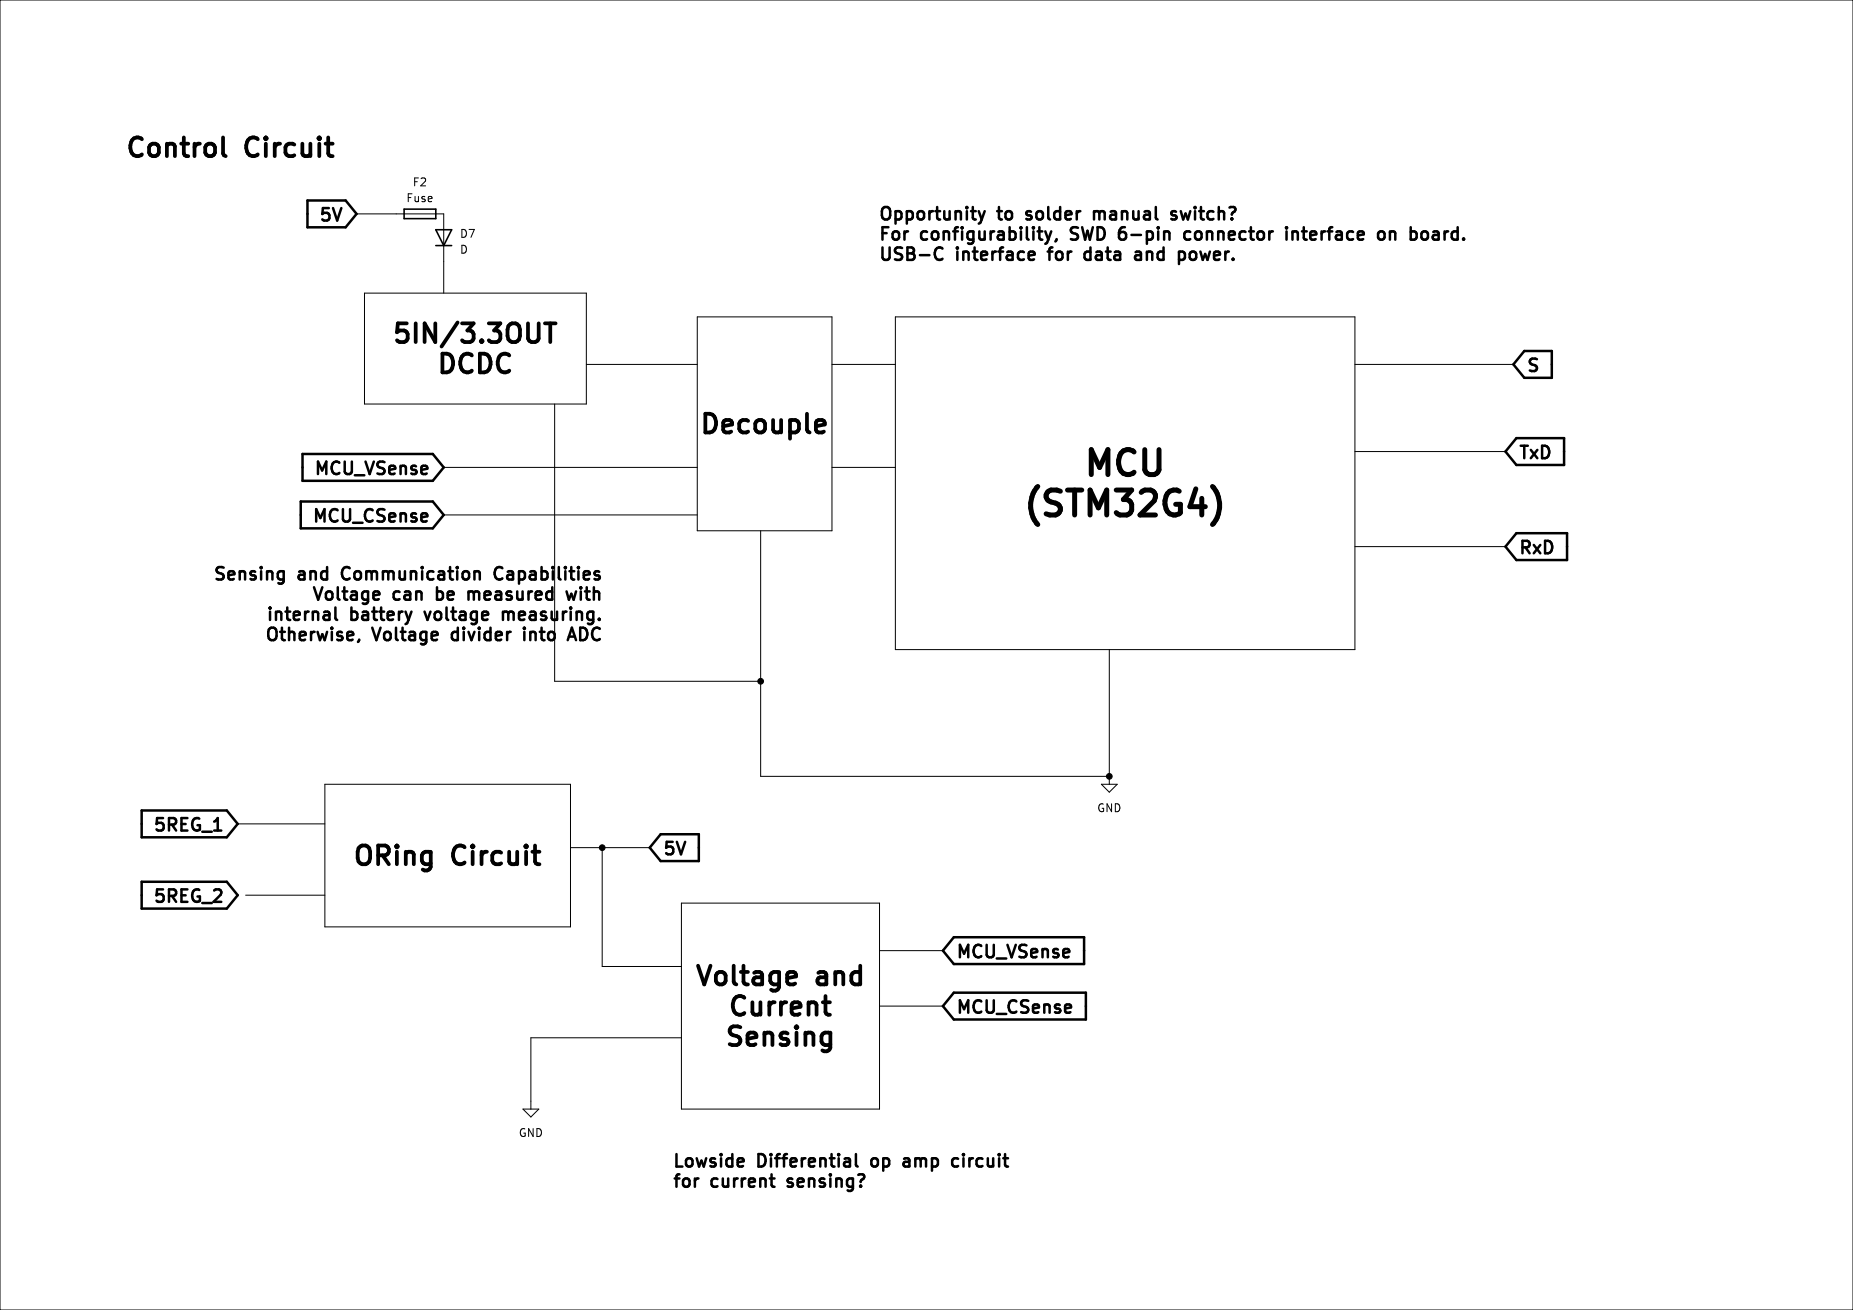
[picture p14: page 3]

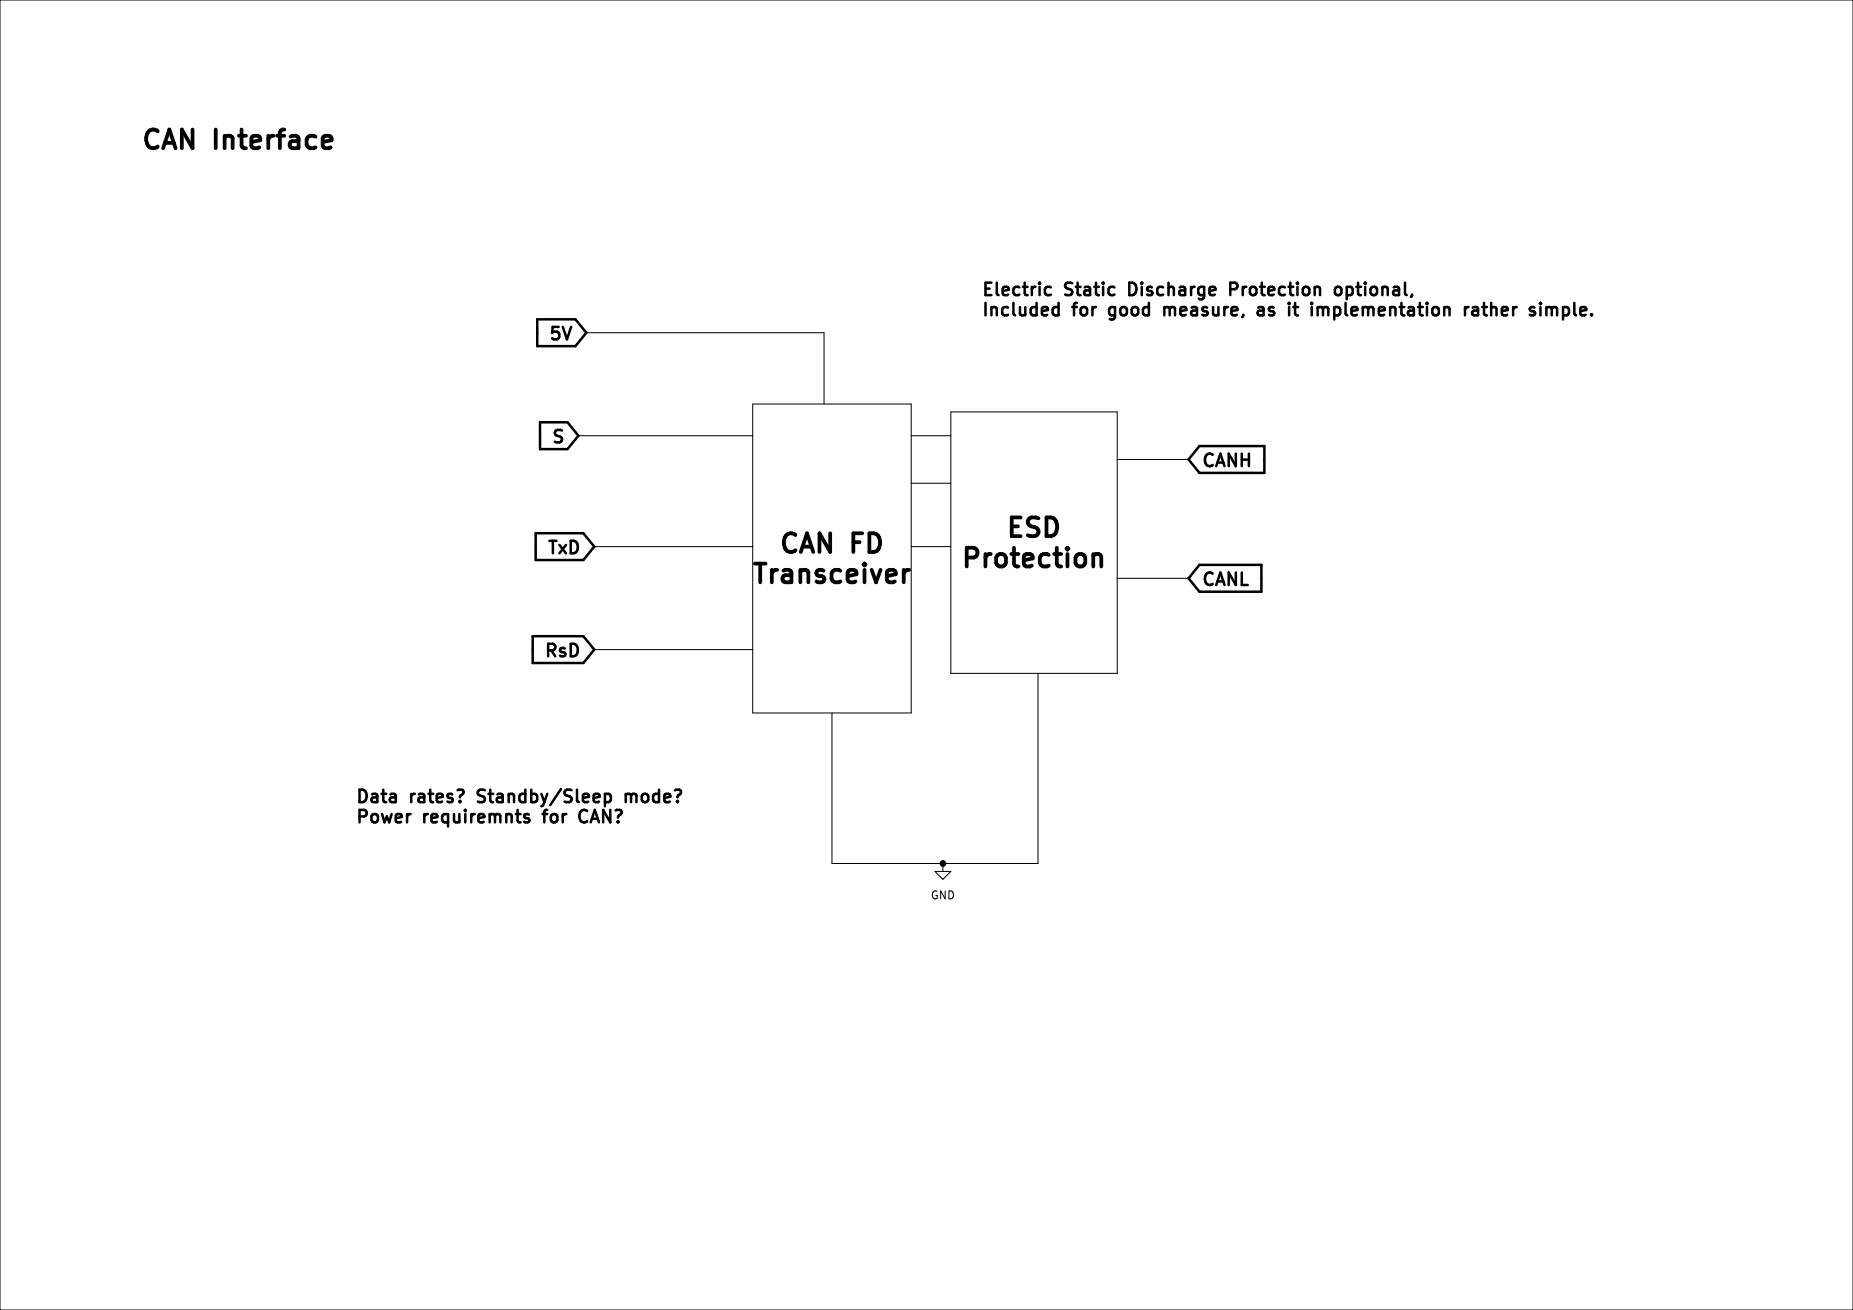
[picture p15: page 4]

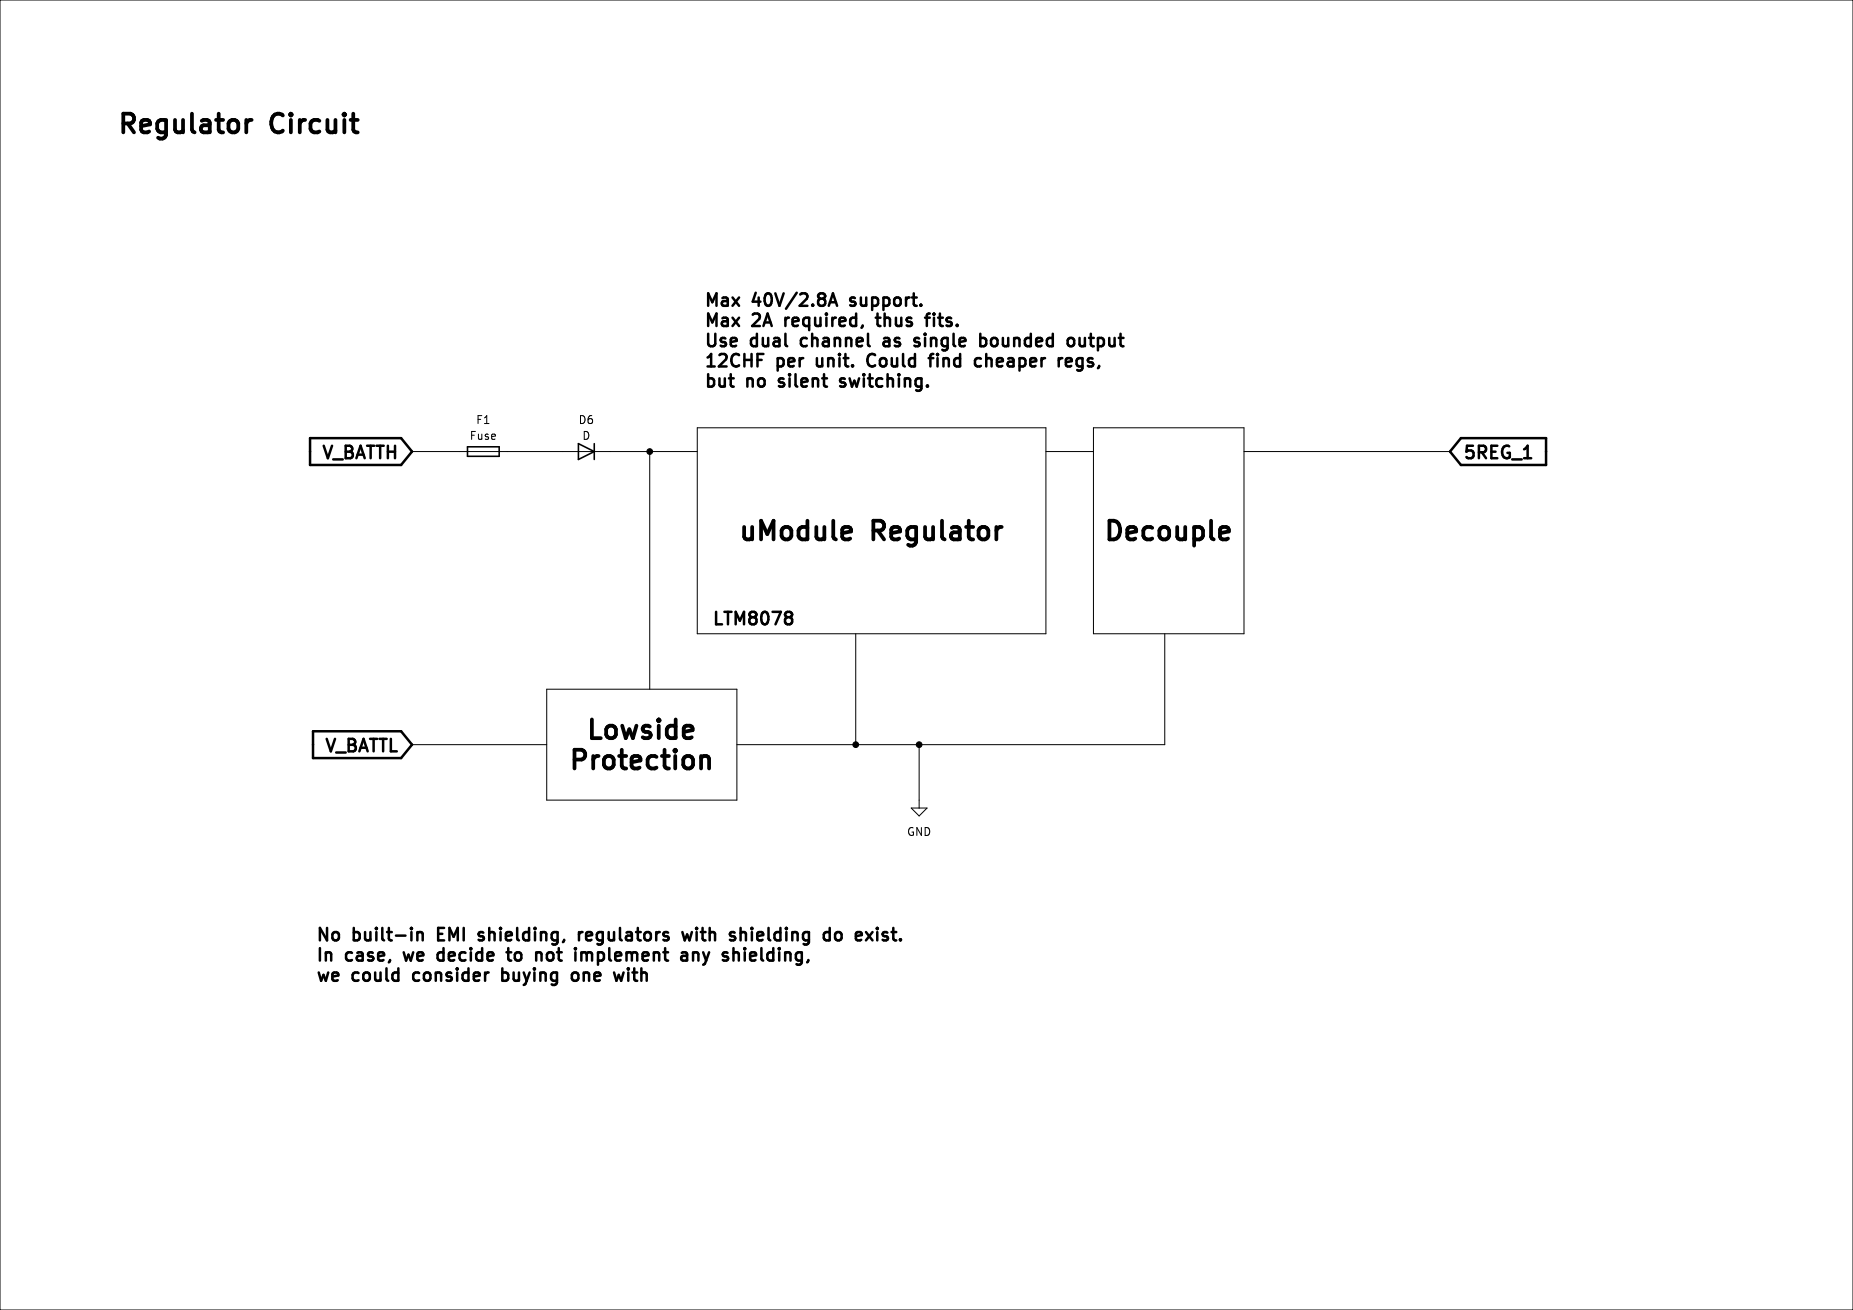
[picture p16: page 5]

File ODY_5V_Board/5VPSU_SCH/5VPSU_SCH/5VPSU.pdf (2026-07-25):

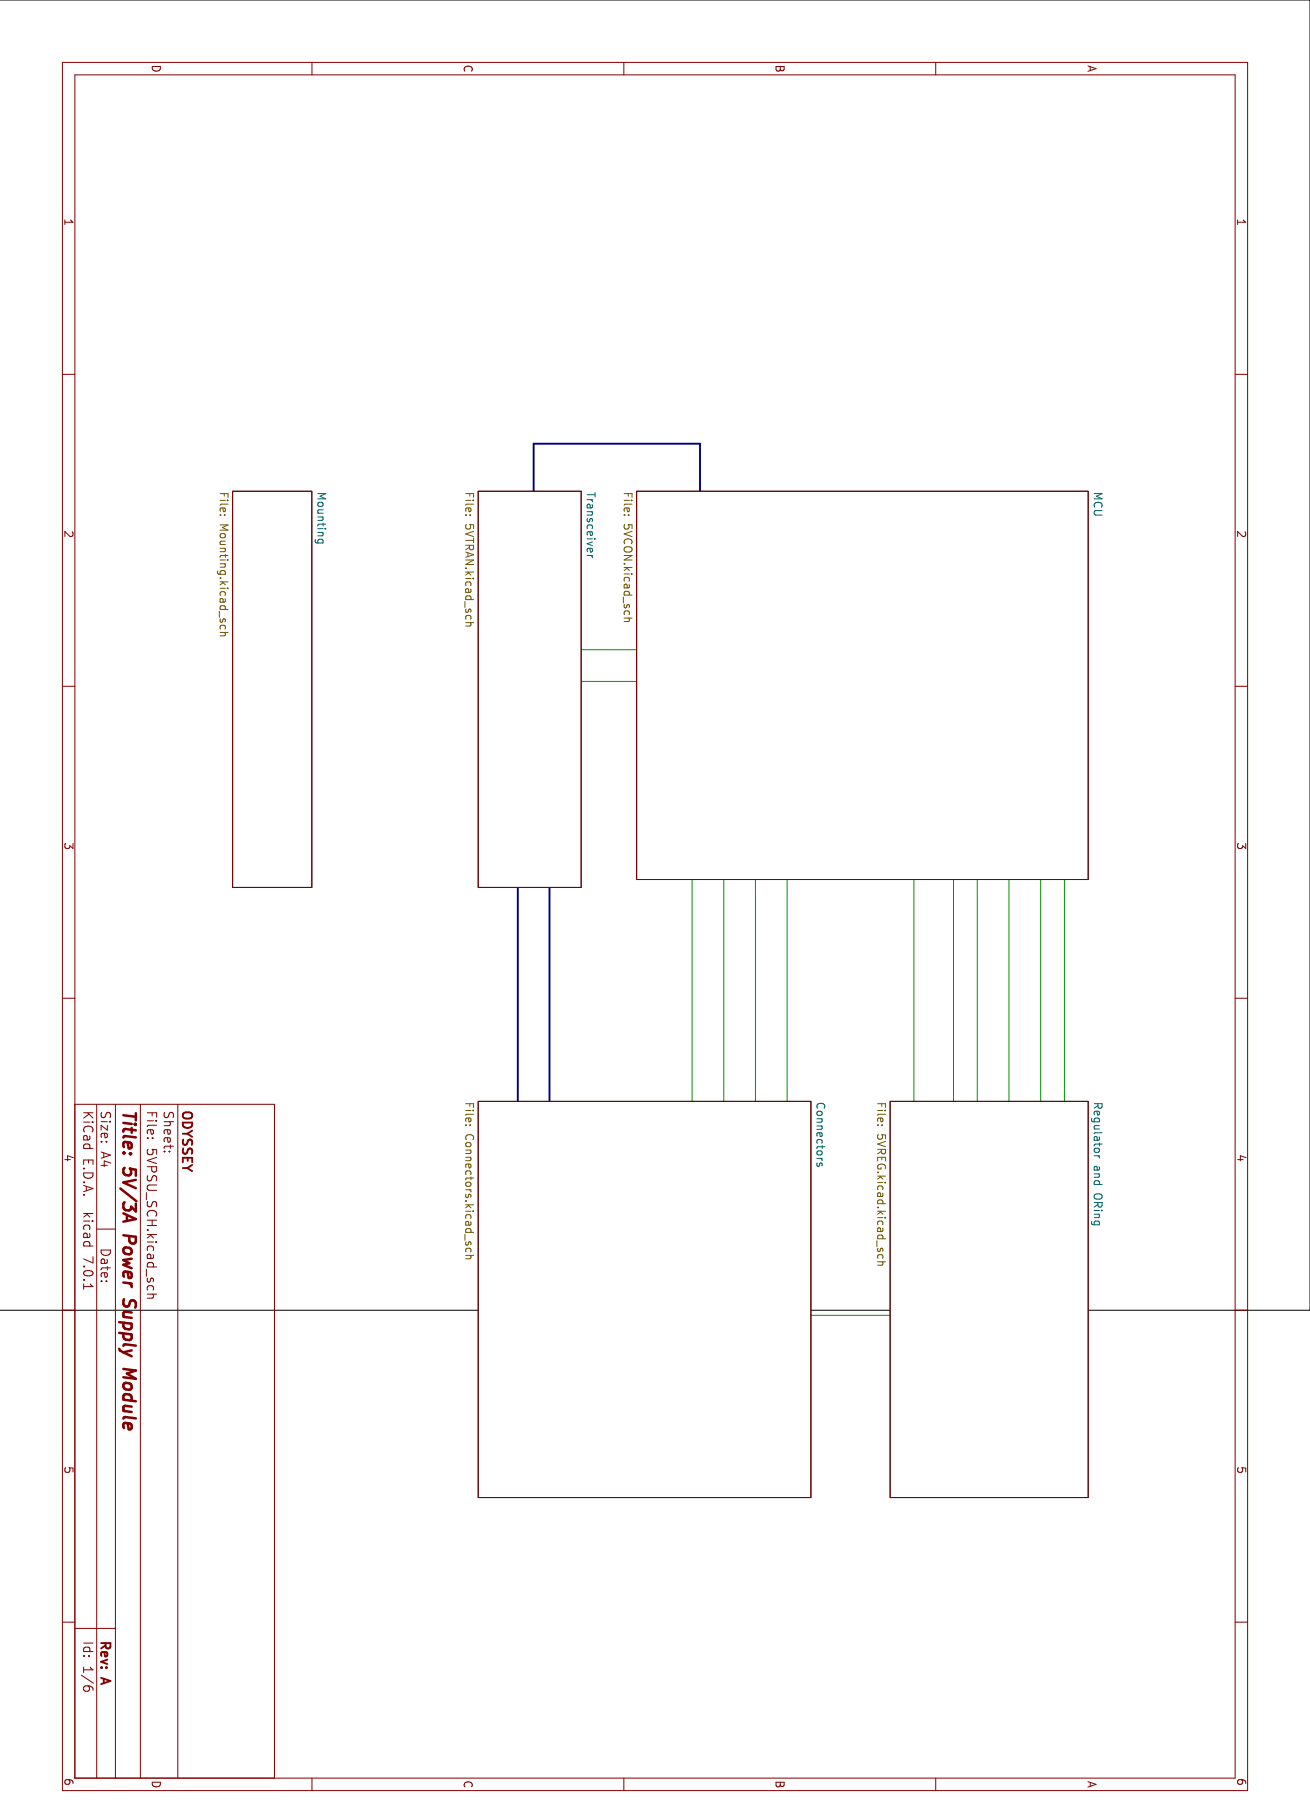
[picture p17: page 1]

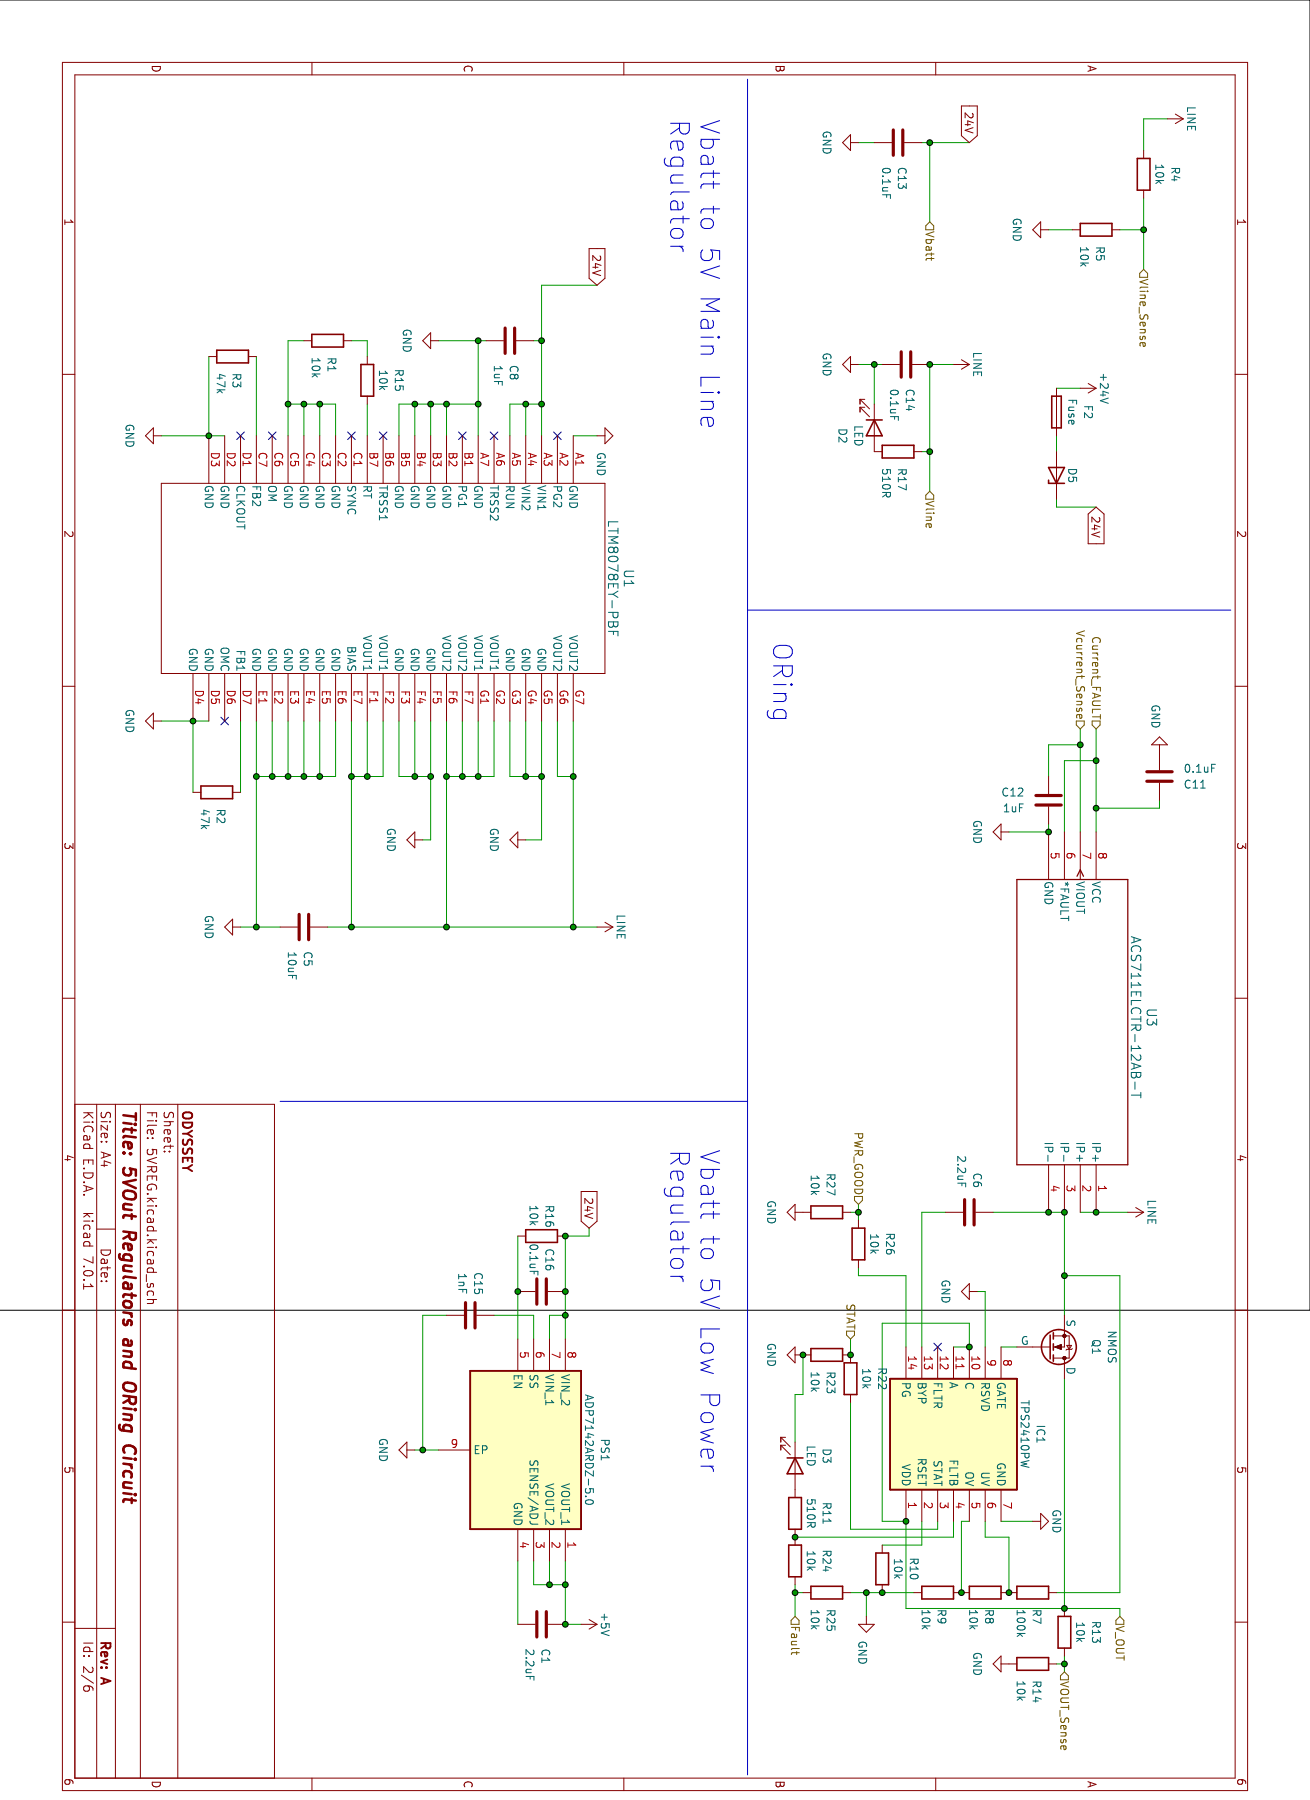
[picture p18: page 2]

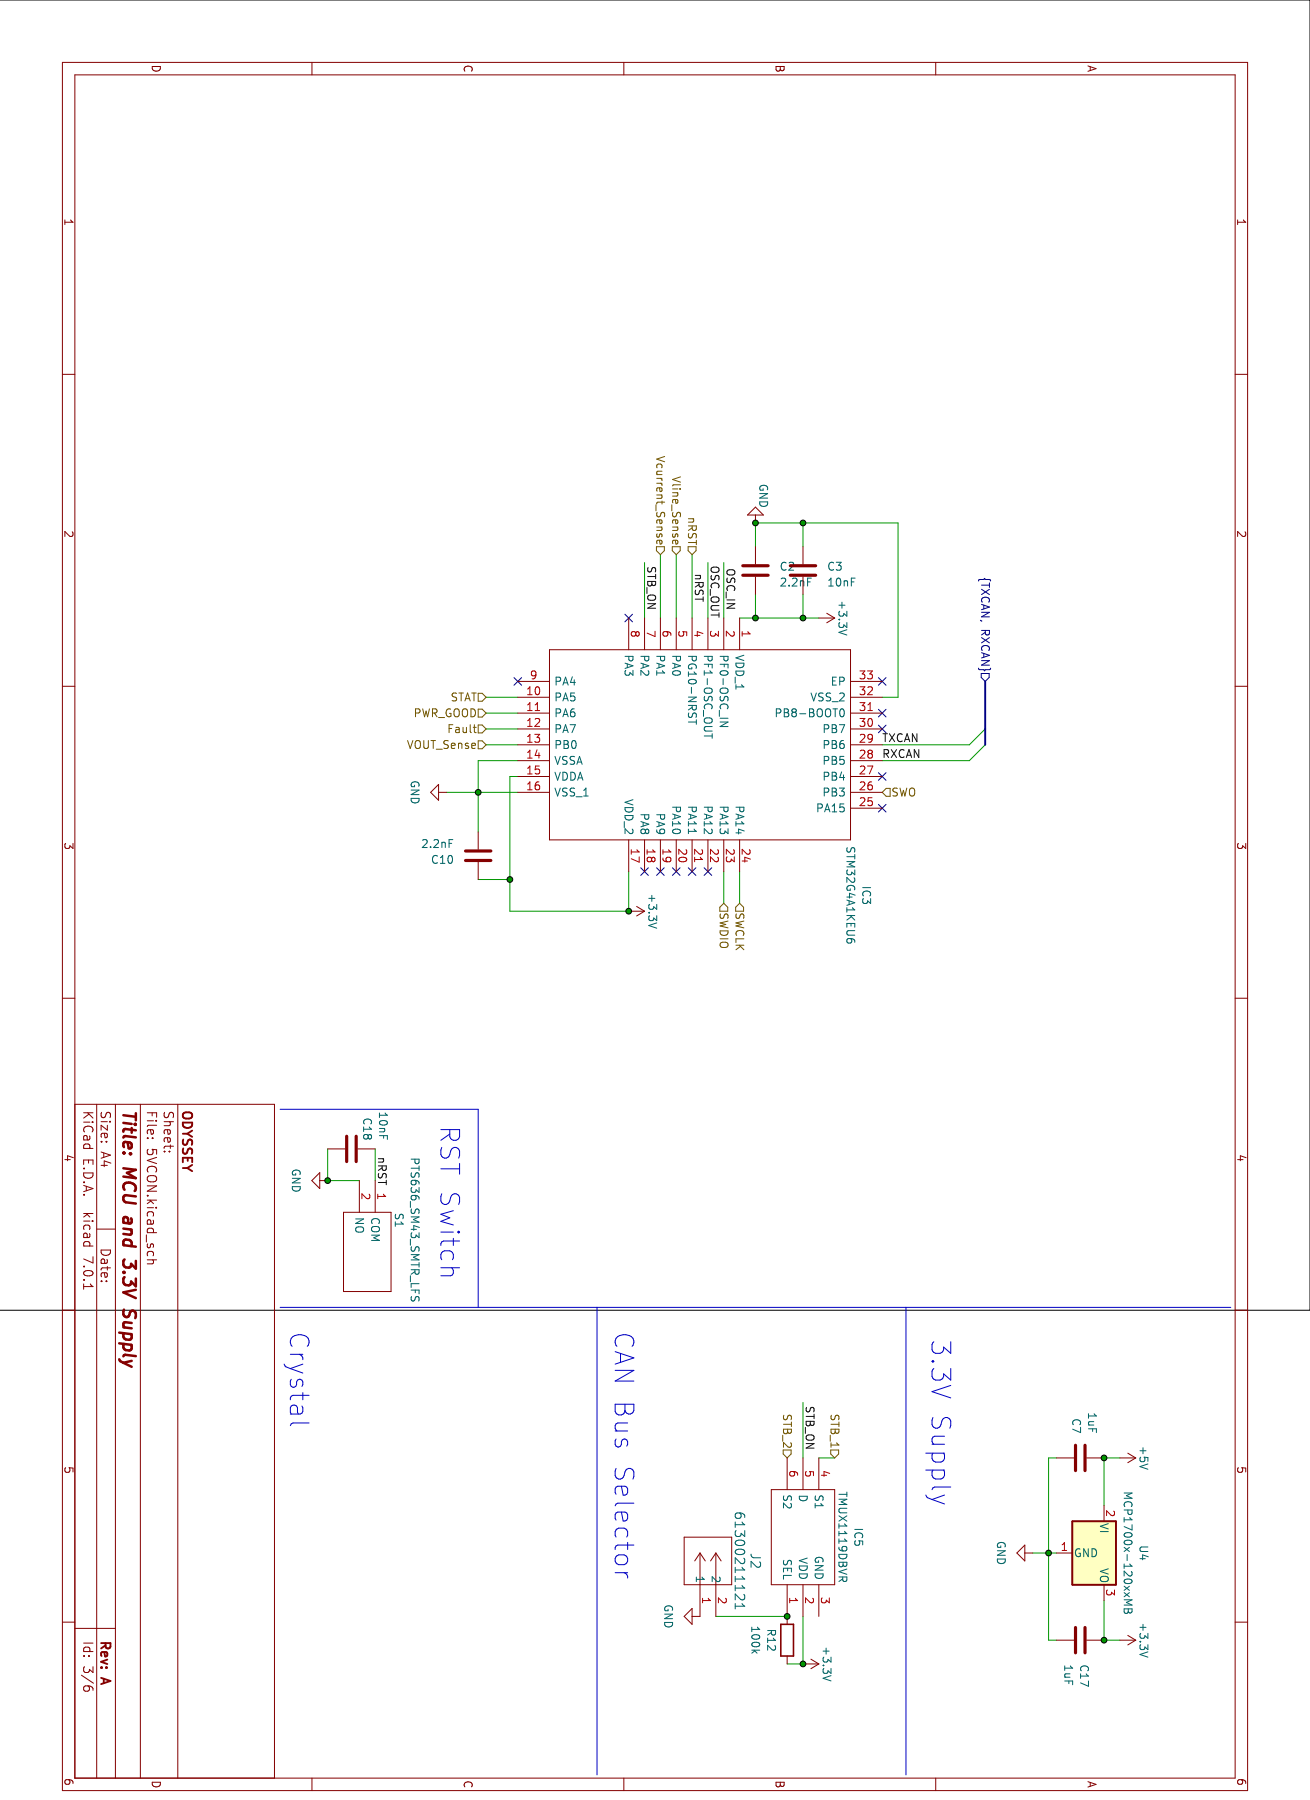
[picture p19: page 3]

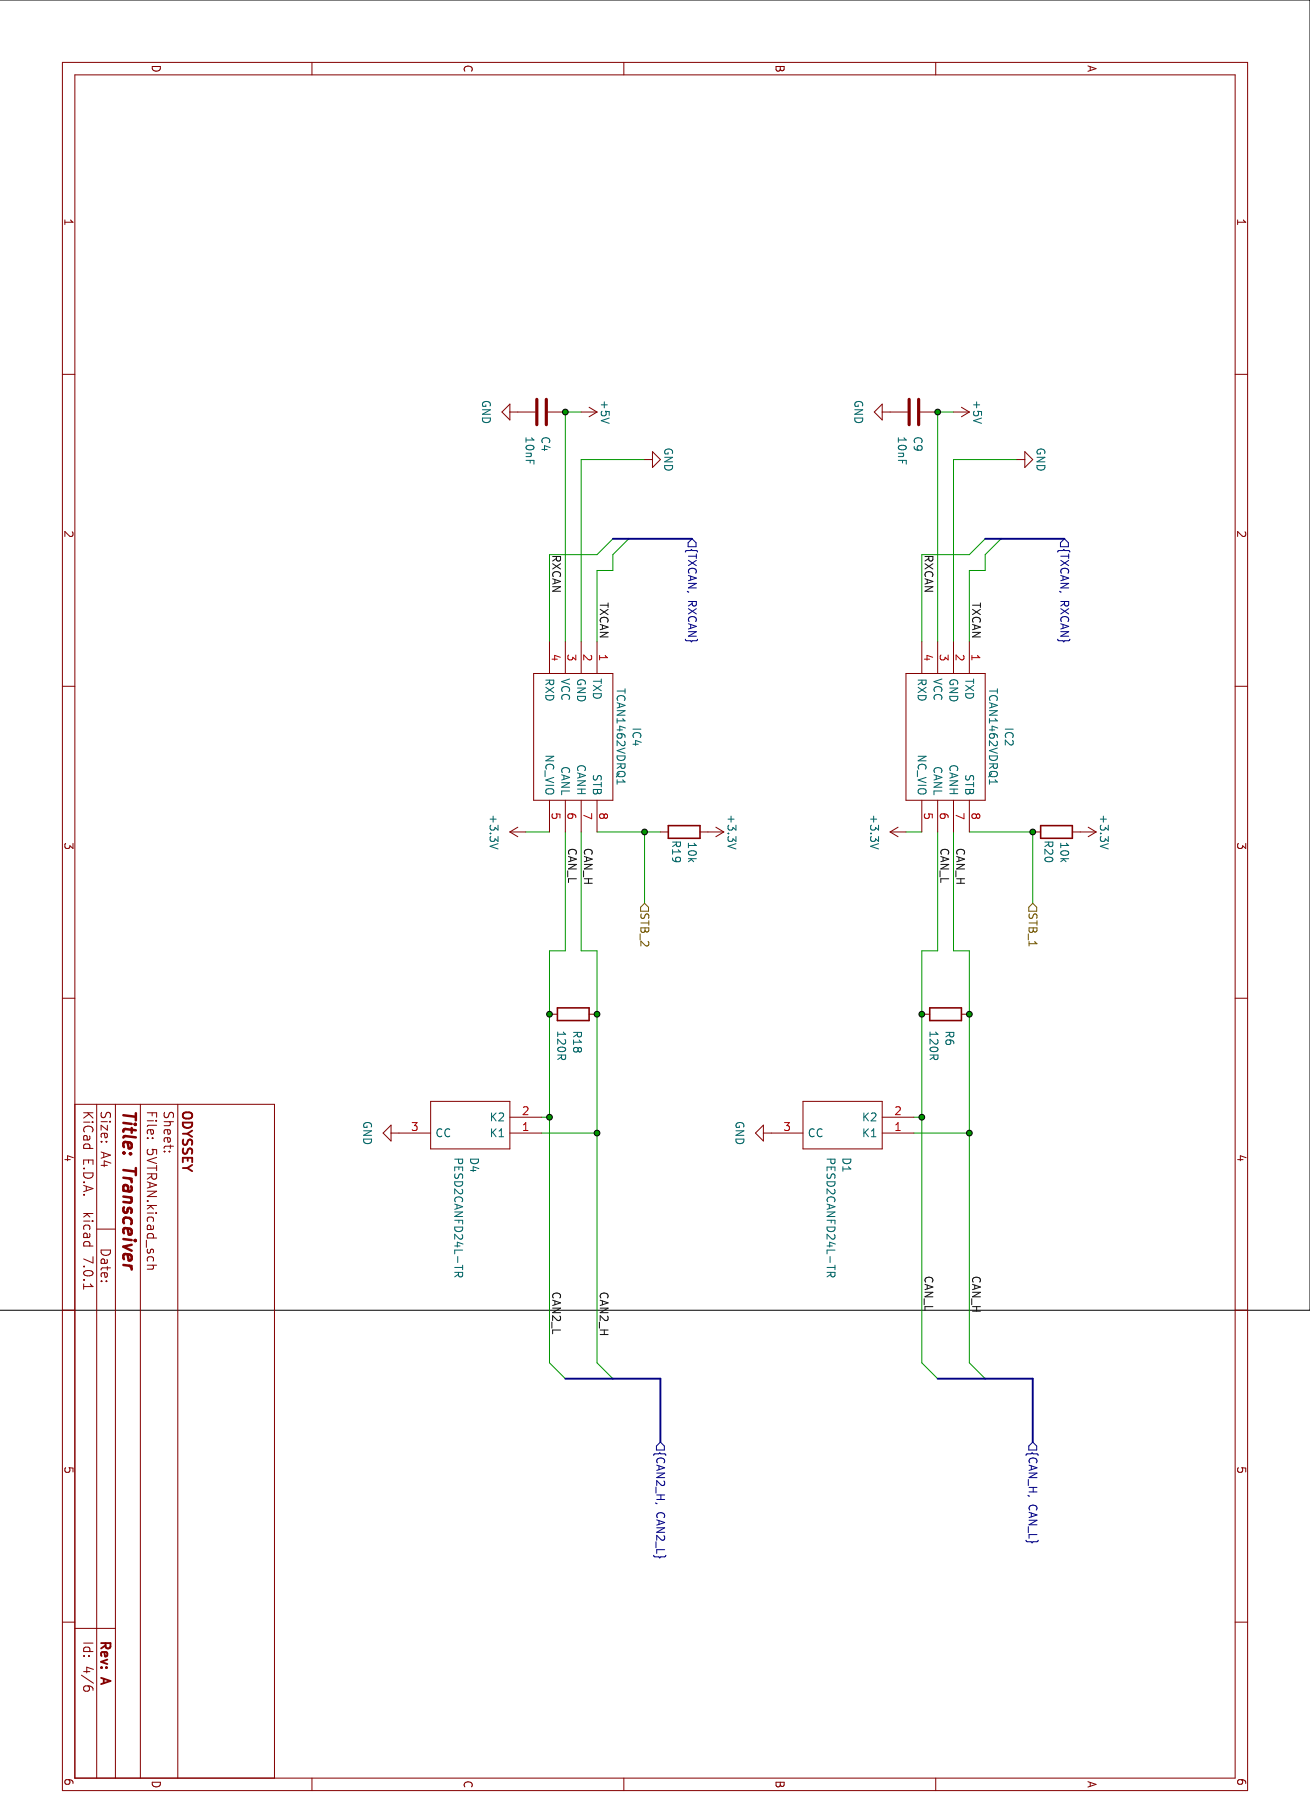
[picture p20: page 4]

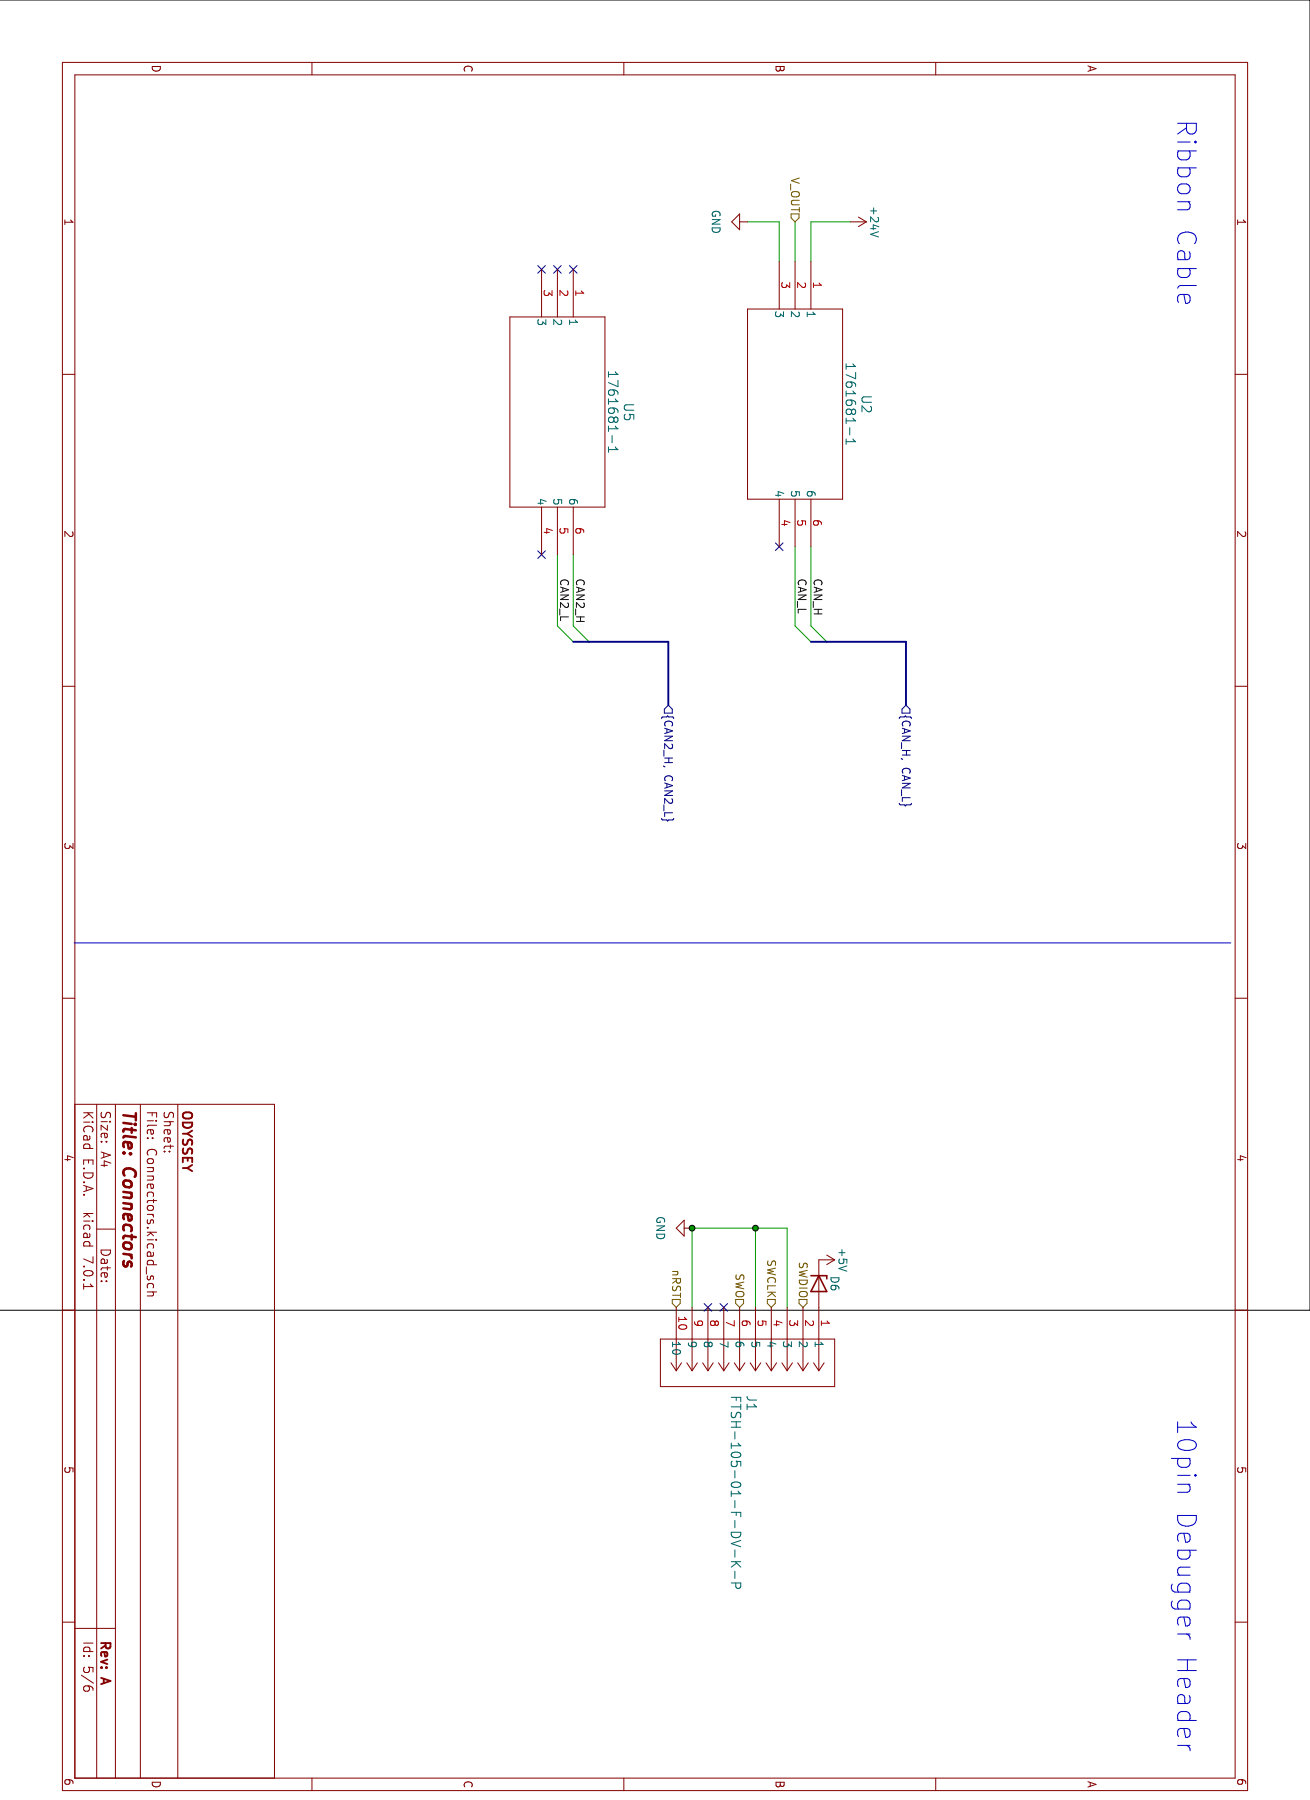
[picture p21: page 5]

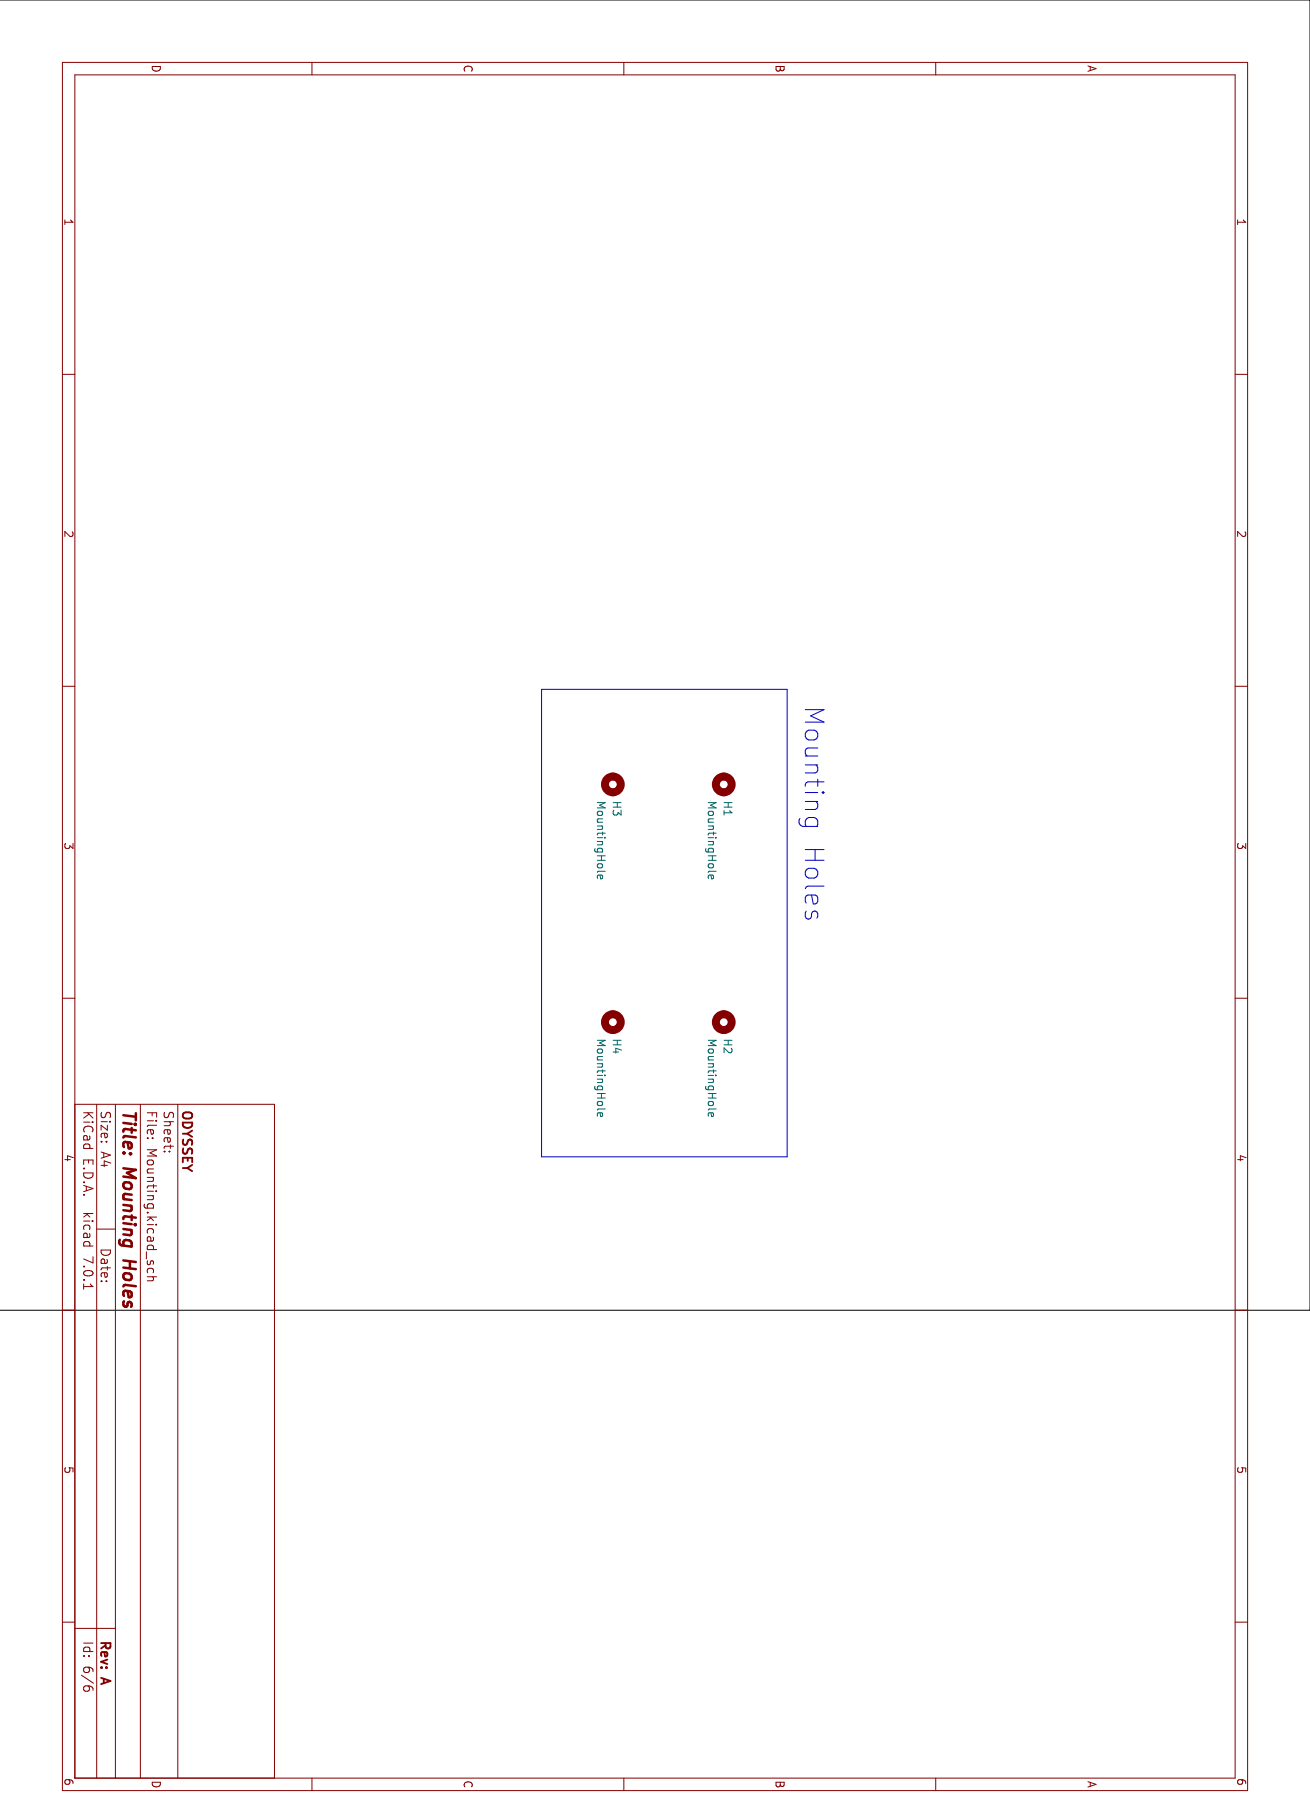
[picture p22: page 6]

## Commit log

2026-07-25 HELVETIA PCB files initial commit
    [RecoveryBoard_V3.SchDoc]
2026-07-25 ODYSSEY Design Files initial commit
    5V power module
    [5REG.kicad.kicad_sch, 5VCON.kicad_sch, 5VPSU_Block.kicad_pcb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]

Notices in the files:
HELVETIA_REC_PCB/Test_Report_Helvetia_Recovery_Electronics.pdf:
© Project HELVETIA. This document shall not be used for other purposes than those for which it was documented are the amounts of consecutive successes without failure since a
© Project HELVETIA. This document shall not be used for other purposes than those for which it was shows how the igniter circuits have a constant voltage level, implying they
